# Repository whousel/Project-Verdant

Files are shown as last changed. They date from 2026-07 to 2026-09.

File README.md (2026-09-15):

# Project Verdant

## Automated Plant Monitoring \& Watering System

#### Giving plants the perfect start.

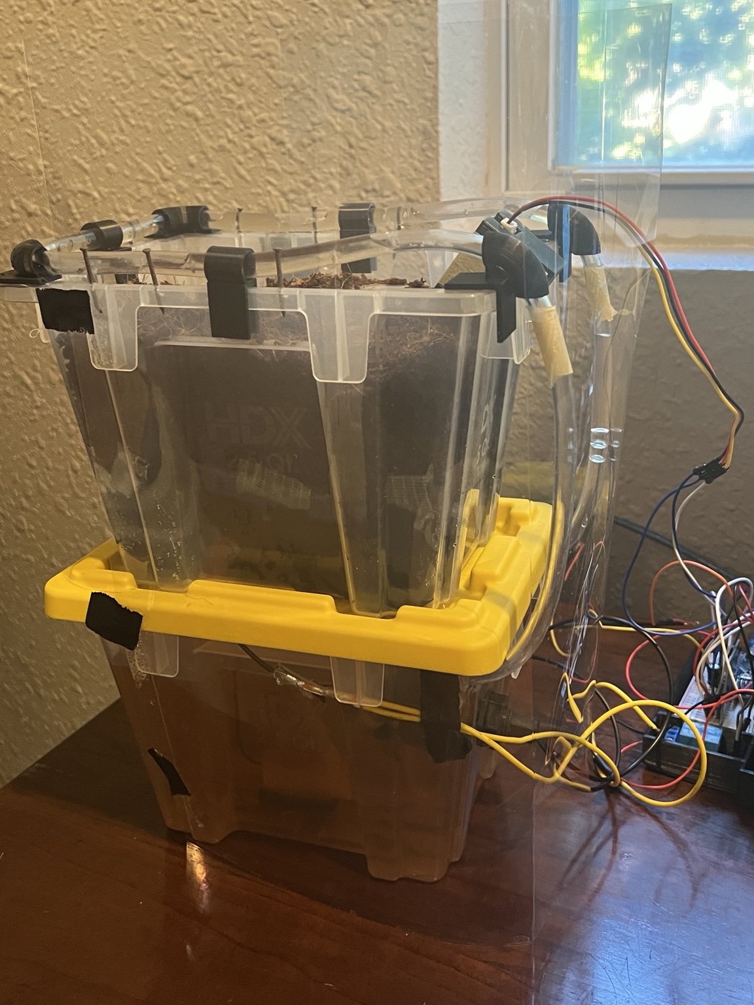
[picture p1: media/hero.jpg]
Project Verdant


### **Overview**

Project Verdant is an automated plant monitoring and watering system designed to reduce the need for manual plant care. The system continuously monitors soil moisture and reservoir water level, automatically activates a pump when the measured moisture falls below the configured threshold, and records system data to a MicroSD card for later analysis.

The project combines embedded software, electronics, CAD, 3D printing, and iterative physical testing into a single autonomous system.

### **Key Features**

\- Automatic soil moisture monitoring

\- Automatic watering based on configurable moisture thresholds

\- Reservoir water-level monitoring

\- MicroSD data logging

\- Pump control through a relay

\- Custom 3D-printed components

\- Distributed water delivery

\- Splash protection for electronics

\- LED status indication for data logging

\- Designed for extended unattended operation

### **How It Works**

The system continuously monitors the growing medium using a capacitive soil moisture sensor. When the measured moisture falls below the configured threshold, the Arduino Nano activates the water pump through a relay.

Water is distributed through multiple openings in the watering tubing to reduce concentrated water flow and provide more consistent coverage. A horizontal float switch monitors the reservoir water level.

Sensor readings and system states are recorded to a MicroSD card, allowing the system's behavior to be analyzed after testing.

```
                 ┌───────────────────┐
                 │ Soil Moisture      │
                 │ Sensor             │
                 └─────────┬─────────┘
                           │
                           ▼
┌───────────────┐    ┌──────────────┐
│ Water Level   │───►│ Arduino Nano │
│ Float Switch  │    └──────┬───────┘
└───────────────┘           │
                            │
             ┌──────────────┼──────────────┐
             │              │              │
             ▼              ▼              ▼
           Pump          MicroSD          LED
           Relay         Logging         Status
             │
             ▼
         Watering
          System
          
```
### **Hardware**

### **Electronics**

* Arduino Nano
* Capacitive soil moisture sensor
* Horizontal magnetic float switch
* Water pump
* Relay
* MicroSD card reader
* MicroSD card
* LED
* Resistor
* Capacitor
* Breadboard
* Jumper wires
* 9V power source

### **Mechanical System**

The prototype uses two 2.5-quart storage containers, one for the growing medium and one for the water reservoir.

Custom 3D-printed components are used to secure and route the pump and tubing, position the soil moisture sensor, and organize the electronics.

A clear acetate splash shield provides an additional layer of protection for the electronics.

CAD files for the custom components are available in the [`hardware/C.A.D`](hardware/C.A.D/) directory.

### **Software**

The Arduino software is responsible for:

1. Reading soil moisture.
2. Monitoring the reservoir water level.
3. Determining when watering is required.
4. Activating and deactivating the pump.
5. Recording sensor and system states.
6. Providing an LED indication of the data-logging state.

The current version uses local MicroSD storage rather than wireless data transfer. This keeps the system simple and allows testing data to be collected without requiring Wi-Fi or a separate application.

The primary project code is available in [`software/ProjectCode`](software/ProjectCode/).

Additional test programs used during development are also included in the [`software`](software/) directory.

### **Testing \& Validation**

Testing was performed iteratively throughout development, beginning with short functional tests and progressing to repeated extended-duration tests.

Three logged tests were completed to evaluate system behavior and sensor stability. Representative raw datasets are included in the [`data`](data/) directory.

### **Extended Monitoring**

During an uninterrupted test lasting approximately 44 minutes, measured soil moisture gradually decreased from approximately 55% to 48%.

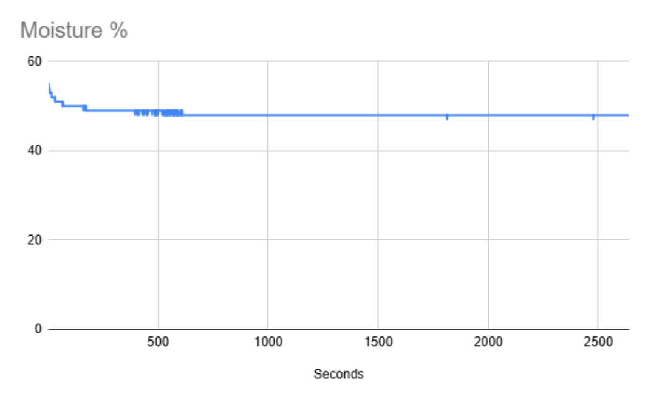
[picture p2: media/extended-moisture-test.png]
Extended moisture monitoring


The readings remained highly stable throughout the test, with no unexpected fluctuations or large measurement jumps.

### **Automatic Watering Response**

The coco coir used during testing retained moisture extremely well, so the system did not naturally reach the configured watering threshold during the extended monitoring tests.

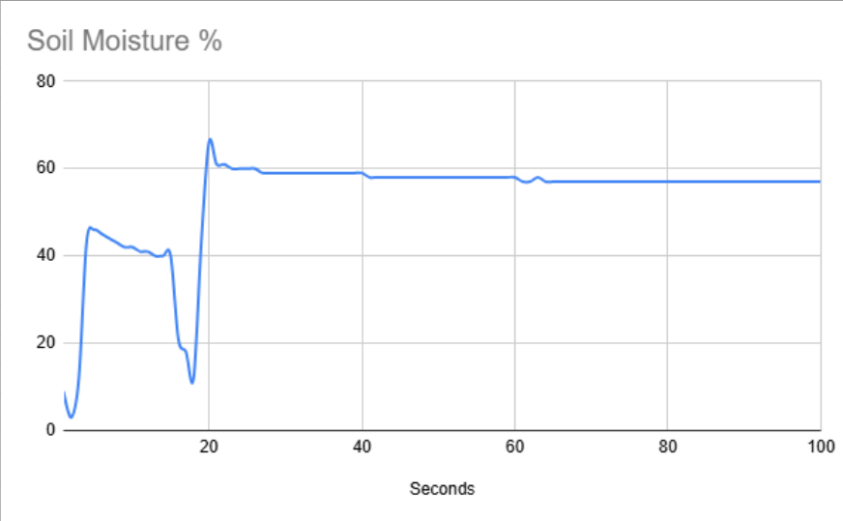
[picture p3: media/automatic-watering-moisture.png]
Automatic watering moisture response


The automatic watering response was therefore separately validated by intentionally removing the soil moisture sensor from the growing medium to simulate a dry condition.

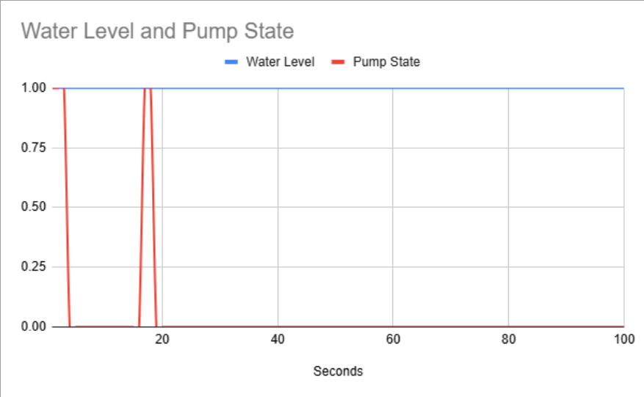
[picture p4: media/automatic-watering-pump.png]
Pump activation and water level


The measured moisture value decreased, causing the pump to activate. Returning the sensor to the growing medium caused the measured moisture value to increase and the pump to stop. This process was repeated multiple times.

The corresponding water-level and pump-state data shows the pump activating during the simulated dry conditions and stopping after the sensor was returned to the growing medium.

Representative raw datasets are available in [`data/`](data/).

### **Development Process**

Project Verdant was developed through repeated physical testing, failure analysis, redesign, and validation.

Several major design changes resulted directly from testing, including:

* Replacing the original water-level sensor with a horizontal float switch.
* Redesigning the watering tubing to address inconsistent water pressure.
* Adding tubing guides to prevent water from escaping the planter.
* Adding a splash shield after a pressure-related water event damaged an Arduino.
* Redesigning the pump holder and other 3D-printed components.
* Adding an LED indicator for MicroSD data logging.
* Adding MicroSD data logging for extended testing.
* Improving electrical connections to prevent intermittent sensor disconnections.

The [`development log`](docs/devlog.md) documents the project's progression from initial prototype through the completed V1 system.

### **Engineering Decisions**

The reasoning behind major hardware and design choices is documented in [`decisions.md`](docs/decisions.md).

These include the choice of:

* A capacitive soil moisture sensor
* A horizontal float switch
* Two stacked storage containers
* MicroSD data logging
* An Arduino Nano
* A splash shield
* Distributed watering tubing and tubing guides

### **Requirements**

The original and completed Version 1 requirements, along with planned future functionality, are documented in [`requirements`](docs/requirements.md).

### **Bill of Materials**

The estimated cost of the prototype is documented in the [`bill of materials`](docs/bill%20of%20materials.md).

Component costs are based on the portion of each purchased component used in the prototype. Multi-packs are accounted for using the estimated cost of the individual components used.

### **Future Development**

Project Verdant is intended to continue beyond the current prototype.

### **Plant Profiles**

Add predefined plant profiles with different moisture requirements. Users will eventually be able to select and modify plant profiles and adjust settings directly on the device or through an application.

### **Environmental Monitoring**

Add temperature and airflow monitoring and eventually incorporate these measurements into plant-care decisions.

### **Improved Watering**

Redesign the watering system to provide more consistent and reproducible water distribution while reducing the amount of manual setup required.

### **User Experience**

Develop a more refined external enclosure, improve the LED indicator system, make the reservoir easier to refill, and improve access to components for maintenance.

### **Safety and Reliability**

Continue improving protection against water and electrical damage and increase the system's ability to operate safely for extended periods without supervision.

### **Expanded Applications**

Explore the use of nutrient-enriched water and potential adaptation of the system for hydroponic and other automated growing applications.

### **Repository Structure**

Project-Verdant/

├── [`software/`](software/) — Arduino source code

├── [`hardware/C.A.D/`](hardware/C.A.D/) — CAD and 3D-printable parts

├── [`data/`](data/) — representative test datasets

├── [`media/`](media/) — project images and test graphs

└── [`docs/`](docs/) — requirements, decisions, development log, and bill of materials

### **Lessons Learned**

Project Verdant has been developed through repeated testing, failure, redesign, and validation.

The most significant lessons came from problems that were not apparent in the initial design. Water pressure, tubing geometry, sensor behavior, electrical connections, and water protection all required physical testing before the system became reliable.

The current prototype is the result of these iterative improvements rather than a single successful build.

### **Current Status**

Version 1 — Functional

The current prototype successfully monitors soil moisture and reservoir level, automatically controls watering, logs system data, and has completed repeated extended-duration tests without water escaping the intended system.

Development of additional features and improvements is ongoing.

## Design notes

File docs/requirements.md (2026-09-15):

# **Project-Verdant  — Requirements**

### **Version 1 — Completed**

##### **Monitoring**

* Continuously monitor soil moisture.
* Monitor the water level of the reservoir.
* Detect when the reservoir is empty or below the required water level.
* Provide a visible LED indicator for the data-logging system.

##### **Automatic Watering**

* Automatically activate the pump when soil moisture falls below the configured threshold.
* Automatically stop watering when the desired moisture level is reached.
* Deliver water through a distributed watering system designed to provide more consistent coverage.
* Keep water contained within the planter and reservoir during operation. 

##### **Data Logging**

* Record soil moisture readings over time.
* Record water-level status.
* Record pump state.
* Store testing data on a microSD card for later analysis.

##### **Reliability and Safety**

* Operate continuously without requiring manual intervention during normal operation.
* Protect the electronics from accidental water exposure.
* Prevent water from escaping the intended watering area.
* Maintain stable operation during extended testing.
* Use a splash shield as an additional layer of protection for the electronics.

##### **Physical Design**

* Use custom 3D-printed components to secure and route system components.
* Secure the pump and watering tubing.
* Provide a compact enclosure for the primary electronics.
* Use removable containers for the reservoir and growing medium.

### **Future Development — Planned**

##### **Plant-Specific Control**

* Add predefined plant profiles with different recommended moisture conditions.
* Allow users to select and modify plant profiles.
* Allow watering thresholds and other settings to be changed directly on the device or through an application.

##### **Environmental Monitoring**

* Add temperature monitoring.
* Add airflow monitoring.
* Use environmental data to improve watering decisions and plant care.

##### **Improved Watering**

* Redesign the watering system for more consistent water distribution.
* Improve pressure regulation and water flow.
* Improve drainage and water routing.
* Make the system easier to refill.

##### **User Experience**

* Develop a more refined external enclosure.
* Improve the LED indicator system and integrate it into the enclosure.
* Improve the overall appearance and organization of the system.
* Make maintenance, refilling, and component access easier.

##### **Safety and Reliability**

* Improve protection against water exposure and electrical damage.
* Improve long-term unattended operation.
* Continue testing toward a system that can safely operate for extended periods without supervision.
* Improve the reliability of mechanical and electrical connections.

##### **Expanded Applications**

* Support nutrient-enriched water when appropriate for the selected growing method.
* Explore adaptation for hydroponic and other automated growing applications.

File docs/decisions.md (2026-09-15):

# Project-Verdant - Decisions

**I plan to replace my current water level sensors with side-mounted float switches -**  This will let me track the water level more accurately, track larger changes in the water level, and allow me to skip the stabilization period associated with my current water level sensor. The float switch will provide a much simpler and immediate indication of the level of water remaining in the reservoir.

**I am using a capacitive soil moisture sensor instead of a resistive sensor -** This is because the capacitive soil moisture sensor is much more accurate than the resistive sensor, and the resistive sensor is prone to electrolysis due to conductive probes exposed directly to soil. This switch should greatly improve the lifespan of the soil moisture sensor.

**I am using 2 2.5-quart storage containers to hold the soil and water, respectively -** I chose to stack and use these two containers because they felt like they were of much better quality than the standard 2.5-quart plastic containers, and because they were made to be stacked. Their improved durability allows me to drill into and modify the containers without fear of their collapse, and it gives me confidence in putting relatively heavy objects in them over extended periods without significant wear.

**I distributed the water across multiple openings in the tubing -** I wanted to avoid concentrating the pump’s output in one location, which could disturb the growing medium and cause uneven watering. Distributing the water across multiple openings allows the water to spread across the growing area more evenly. This design is functional for the current prototype, but I plan to replace it with a more consistent watering method in a future version because manually creating and sizing the openings is difficult to reproduce consistently.

**I added nails to guide the watering tubing over the planter walls -** When the pump starts or stops, the water pressure temporarily changes and water can run along the outside of the tubing instead of exiting through the intended holes. Without a guide, this water could run over the edge of the planter and onto the surrounding surface. The nails guide the tubing over the planter so that any water following the outside of the tubing remains within the growing area.

**I added a clear acetate splash shield around the electronics -** During testing, a sudden increase in water pressure caused water to spray throughout the system and damaged an Arduino. I added the splash shield to prevent water from reaching the electronics if another pressure-related issue occurs. Although later improvements reduced the likelihood of water escaping the intended area, I decided to keep the splash shield as an additional layer of protection.

**I am using a MicroSD card for data logging instead of wireless data transfer -** I chose MicroSD logging because it allows the system to record data without requiring Wi-Fi, a network connection, or a separate application. This keeps the system simpler and easier to deploy while still allowing me to collect and analyze data after testing. The MicroSD module was also inexpensive and straightforward to integrate with the Arduino Nano.

**I am using an Arduino Nano as the primary microcontroller -** The Nano provides enough inputs and outputs for the sensors, pump control, LED, and MicroSD module used in this project while being significantly smaller and less expensive than larger Arduino boards. The additional capabilities of a larger board were not necessary for the requirements of Version 1.

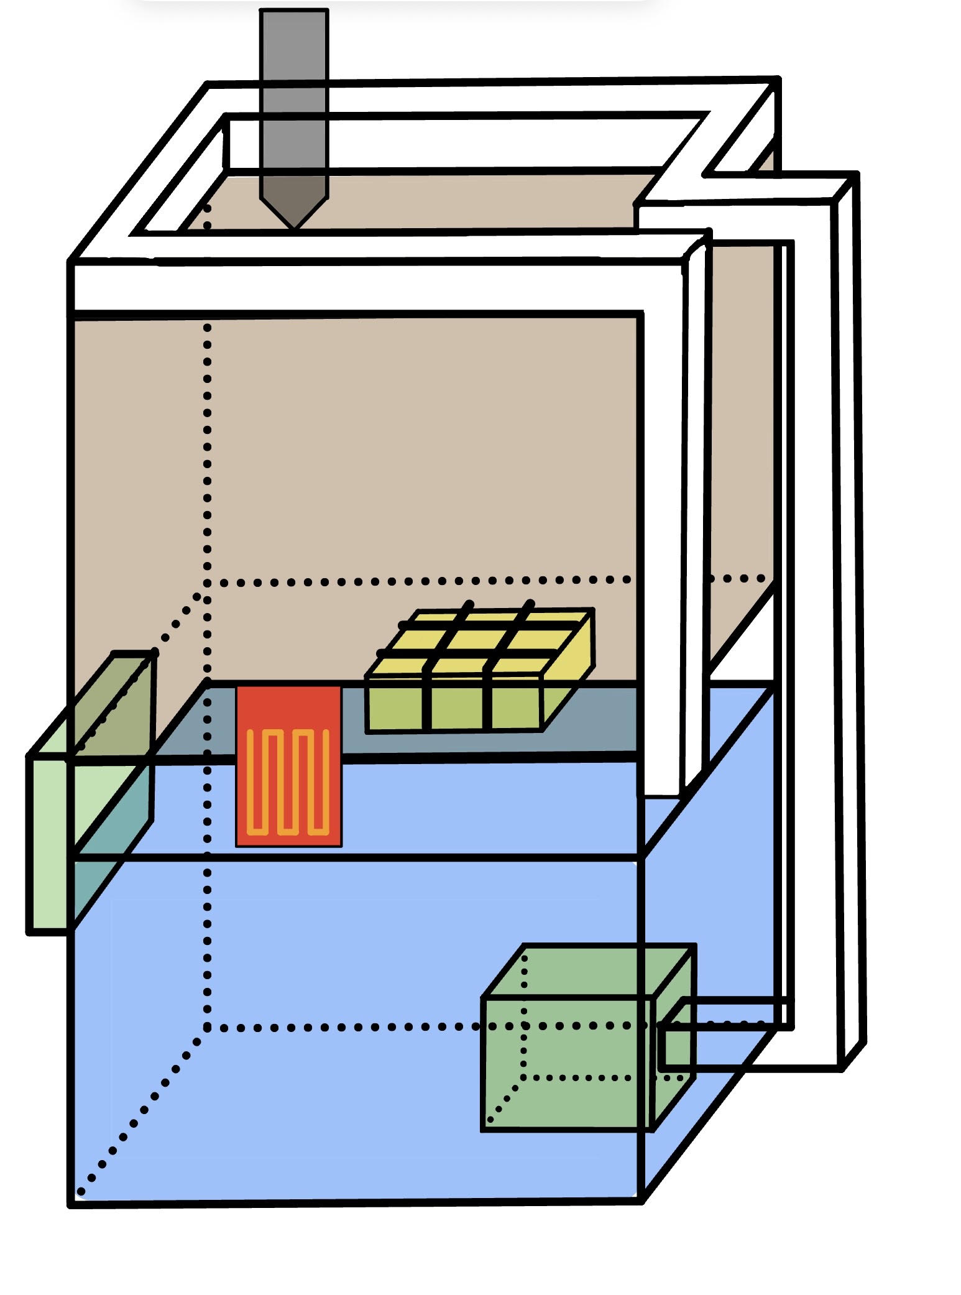
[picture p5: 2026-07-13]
media/Prototype Version 1.jpg

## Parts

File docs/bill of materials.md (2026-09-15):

# Project-Verdant - Bill of Material

#### 

#### **Electronics**

|**Component**|**Quantity**|**Estimated Cost**|
|-|-|-|
|Arduino Nano|1|$4.00|
|Breadboard|1|$2.50|
|Capacitive soil moisture sensor|1|Included in $4.00 bundle|
|Horizontal float switch|1|$3.00|
|Water pump|1|Included in $4.00 bundle|
|Relay|1|Included in $4.00 bundle|
|SD card reader module|1|$1.20|
|MicroSD card|1|$10.00|
|LED|1|\~$0.10|
|Resistor|1|\~$0.10|
|Capacitor|1|\~$0.10|
|Jumper wires|Several|\~$0.25|
|9V battery and connector|1|\~$1.50|

#### **Mechanical Components**

|**Component**|**Quantity**|**Estimated Cost**|
|-|-|-|
|Screws / fasteners|Several|\~$0.25|
|2.5-quart containers|2|$5.00|
|Clear tubing|\~3 ft|\~$0.78|
|Nails|Several|\~$0.10|
|3D-printing filament|\~100 grams|\~2|
|Clear acetate sheet|1|TBD|
|Coco coir / growing medium|—|\~$1.00|

##### **Cost Notes**

Component costs are estimated from the purchase price of the materials used in the prototype. When components were purchased in multi-packs, the estimated cost of one component was used rather than the full package price. Small consumables such as filament, nails, screws, resistors, and LEDs are estimated based on the portion actually used in the prototype.

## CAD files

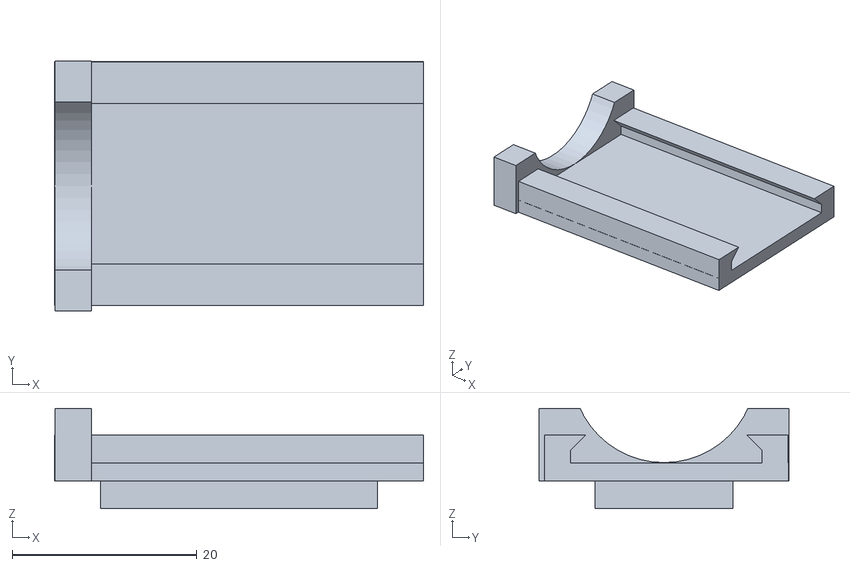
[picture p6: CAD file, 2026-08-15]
hardware/C.A.D/Pump holder v2.stl
40.0 x 27.1 x 10.9

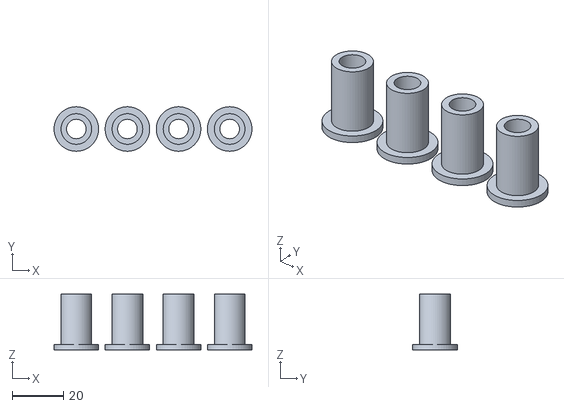
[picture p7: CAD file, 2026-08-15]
hardware/C.A.D/Drainage hole Aligners.stl
77.5 x 17.5 x 21.8

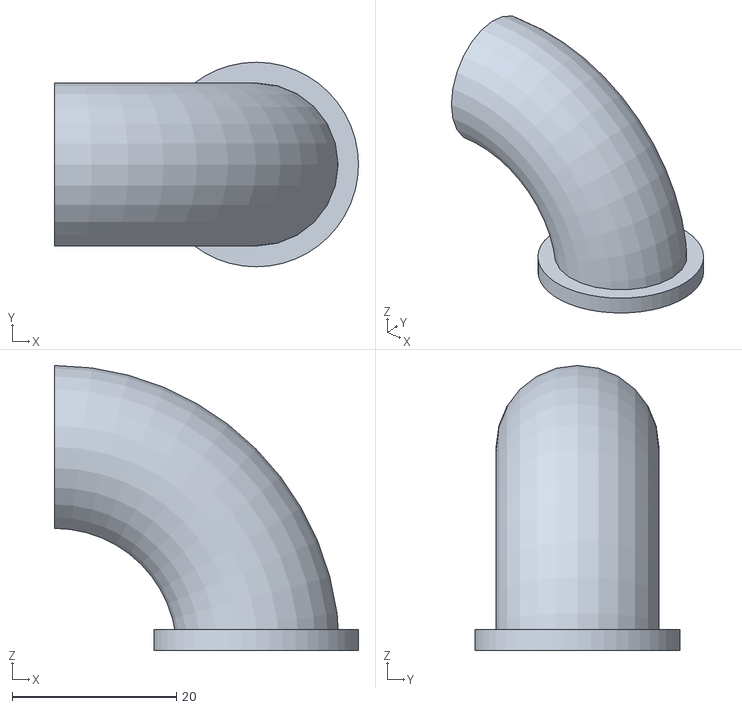
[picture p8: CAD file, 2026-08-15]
hardware/C.A.D/Water Pump Excess Tubing.stl
37.0 x 24.9 x 34.7

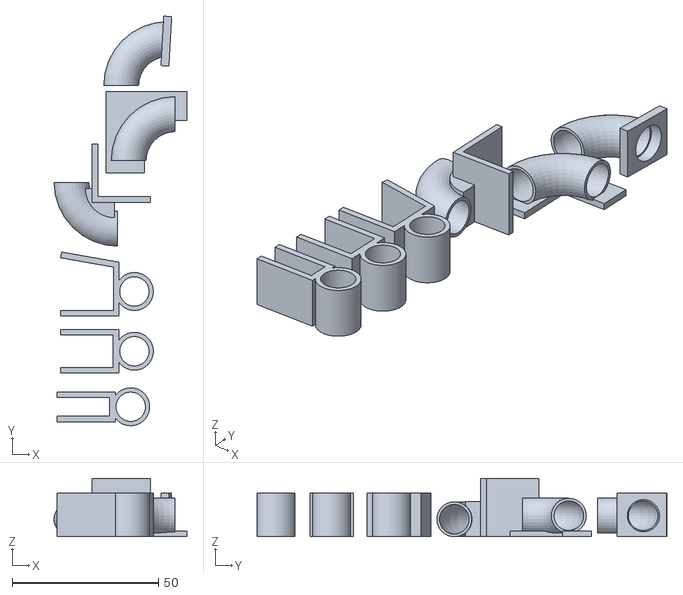
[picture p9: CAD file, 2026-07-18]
hardware/C.A.D/Update Tube Routing Clips.stl
45.5 x 140.1 x 20.0

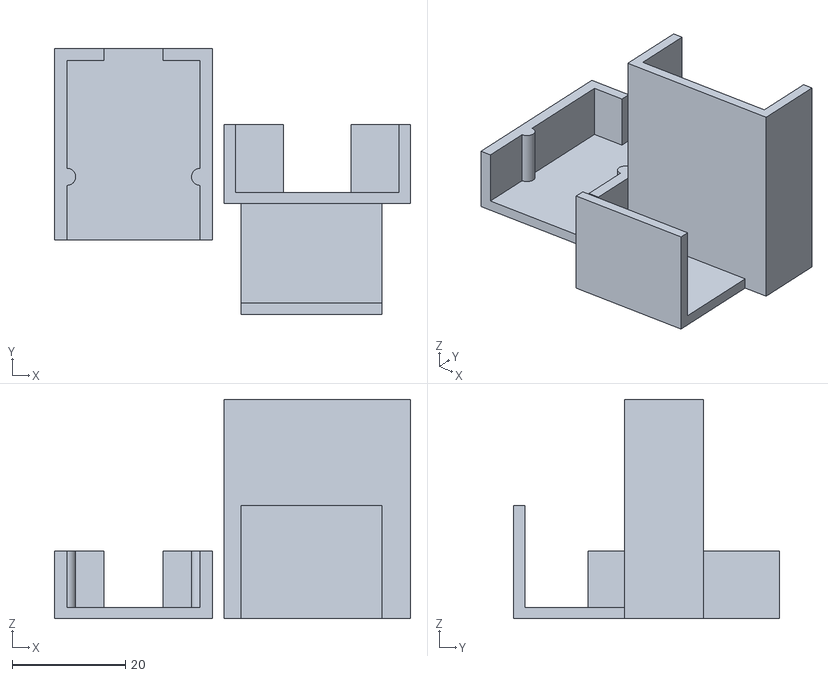
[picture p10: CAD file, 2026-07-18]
hardware/C.A.D/Soil Moisture Sensor Holder - Test.stl
63.0 x 47.0 x 38.8

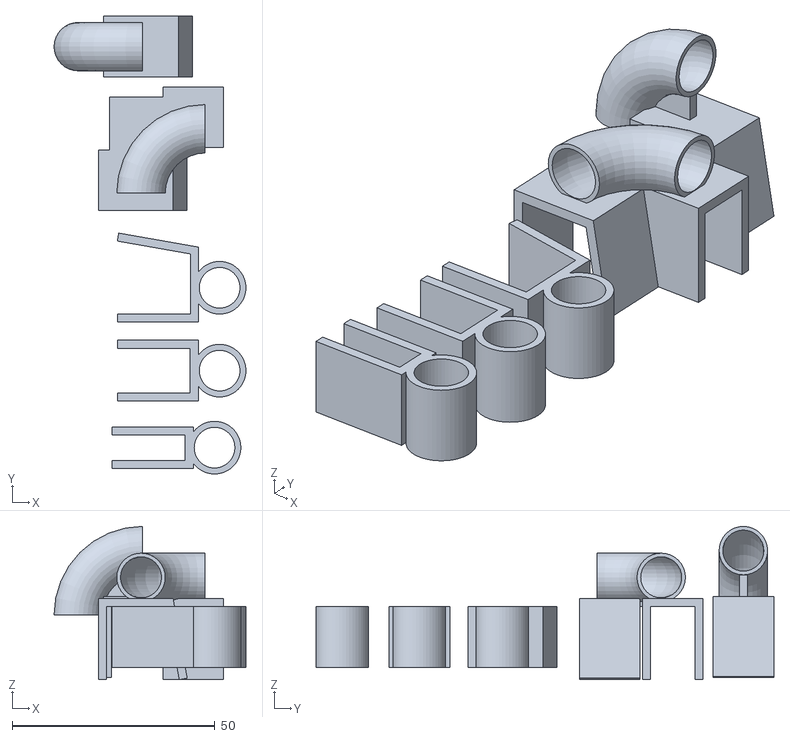
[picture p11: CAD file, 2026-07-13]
hardware/C.A.D/Watering Tubing Clip - Test.stl
47.4 x 113.0 x 37.8

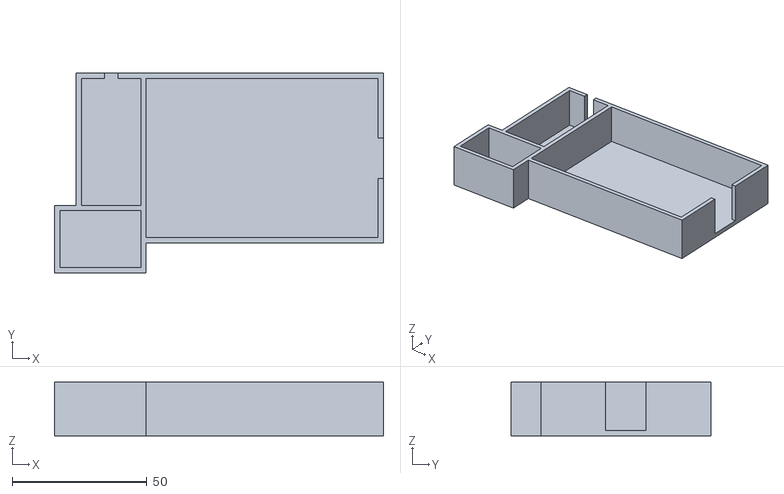
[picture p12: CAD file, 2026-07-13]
hardware/C.A.D/Arduino Prototype Housing - Test.stl
122.0 x 74.0 x 20.0

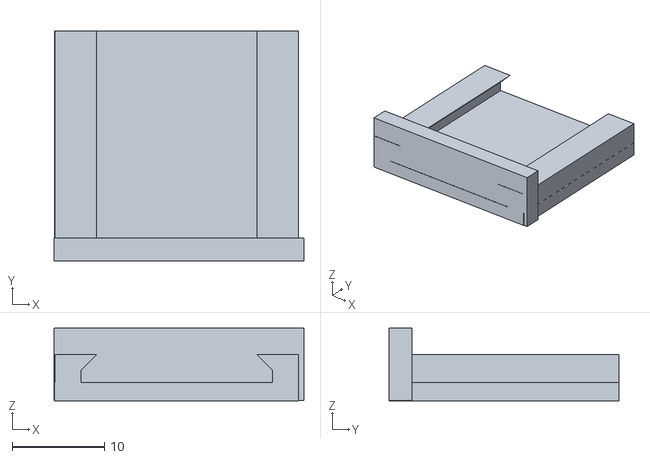
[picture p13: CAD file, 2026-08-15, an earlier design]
hardware/C.A.D/Pump holder v1.stl
27.1 x 25.0 x 7.88

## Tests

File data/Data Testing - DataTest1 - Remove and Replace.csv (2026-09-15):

Seconds | Moisture % | Water Level | Pump State
1 | 23 | 1 | 0
2 | 23 | 1 | 0
3 | 23 | 1 | 0
4 | 23 | 1 | 0
5 | 23 | 1 | 0
6 | 23 | 1 | 0
7 | 23 | 1 | 0
8 | 23 | 1 | 0
9 | 22 | 1 | 0
10 | 3 | 1 | 1
11 | 0 | 1 | 1
12 | 0 | 1 | 1
13 | 0 | 1 | 1
14 | 0 | 1 | 1
15 | 0 | 1 | 1
16 | 0 | 1 | 1
17 | 11 | 1 | 1
18 | 36 | 1 | 0
19 | 40 | 1 | 0
20 | 40 | 1 | 0
21 | 40 | 1 | 0
22 | 40 | 1 | 0
23 | 15 | 1 | 1
24 | 7 | 1 | 1
25 | 6 | 1 | 1
26 | 6 | 1 | 1
27 | 6 | 1 | 1
28 | 10 | 1 | 1
29 | 37 | 1 | 0
30 | 36 | 1 | 0
31 | 35 | 1 | 0
32 | 33 | 1 | 0
33 | 32 | 1 | 0
34 | 31 | 1 | 0
35 | 30 | 1 | 0
36 | 30 | 1 | 0
37 | 29 | 1 | 0
38 | 29 | 1 | 0
39 | 28 | 1 | 0
40 | 28 | 1 | 0
41 | 28 | 1 | 0
42 | 28 | 1 | 0
43 | 27 | 1 | 0
44 | 27 | 1 | 0
45 | 27 | 1 | 0
46 | 26 | 1 | 0
47 | 26 | 1 | 0
48 | 26 | 1 | 0
49 | 26 | 1 | 0
50 | 26 | 1 | 0
51 | 26 | 1 | 0
52 | 26 | 1 | 0
53 | 26 | 1 | 0
54 | 25 | 1 | 0
55 | 25 | 1 | 0
56 | 25 | 1 | 0
57 | 25 | 1 | 0
58 | 25 | 1 | 0
59 | 25 | 1 | 0
60 | 25 | 1 | 0
61 | 25 | 1 | 0
62 | 25 | 1 | 0
63 | 24 | 1 | 0
64 | 26 | 1 | 0
65 | 27 | 1 | 0
66 | 25 | 1 | 0
67 | 40 | 1 | 0
68 | 32 | 1 | 0
69 | 32 | 1 | 0
70 | 32 | 1 | 0
71 | 32 | 1 | 0
72 | 30 | 1 | 0
73 | 30 | 1 | 0
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

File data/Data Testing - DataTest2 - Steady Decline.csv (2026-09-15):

Seconds | Moisture % | Water Level | Pump State
1 | 55 | 1 | 0
2 | 55 | 1 | 0
3 | 55 | 1 | 0
4 | 54 | 1 | 0
5 | 54 | 1 | 0
6 | 54 | 1 | 0
7 | 54 | 1 | 0
8 | 53 | 1 | 0
9 | 53 | 1 | 0
10 | 53 | 1 | 0
11 | 53 | 1 | 0
12 | 53 | 1 | 0
13 | 53 | 1 | 0
14 | 53 | 1 | 0
15 | 53 | 1 | 0
16 | 53 | 1 | 0
17 | 52 | 1 | 0
18 | 52 | 1 | 0
19 | 52 | 1 | 0
20 | 52 | 1 | 0
21 | 52 | 1 | 0
22 | 52 | 1 | 0
23 | 52 | 1 | 0
24 | 52 | 1 | 0
25 | 52 | 1 | 0
26 | 52 | 1 | 0
27 | 52 | 1 | 0
28 | 52 | 1 | 0
29 | 52 | 1 | 0
30 | 52 | 1 | 0
31 | 51 | 1 | 0
32 | 52 | 1 | 0
33 | 52 | 1 | 0
34 | 51 | 1 | 0
35 | 51 | 1 | 0
36 | 51 | 1 | 0
37 | 51 | 1 | 0
38 | 51 | 1 | 0
39 | 51 | 1 | 0
40 | 51 | 1 | 0
41 | 51 | 1 | 0
42 | 51 | 1 | 0
43 | 51 | 1 | 0
44 | 51 | 1 | 0
45 | 51 | 1 | 0
46 | 51 | 1 | 0
47 | 51 | 1 | 0
48 | 51 | 1 | 0
49 | 51 | 1 | 0
50 | 51 | 1 | 0
51 | 51 | 1 | 0
52 | 51 | 1 | 0
53 | 51 | 1 | 0
54 | 51 | 1 | 0
55 | 51 | 1 | 0
56 | 51 | 1 | 0
57 | 51 | 1 | 0
58 | 51 | 1 | 0
59 | 51 | 1 | 0
60 | 51 | 1 | 0
61 | 51 | 1 | 0
62 | 51 | 1 | 0
63 | 51 | 1 | 0
64 | 51 | 1 | 0
65 | 51 | 1 | 0
66 | 50 | 1 | 0
67 | 50 | 1 | 0
68 | 50 | 1 | 0
69 | 51 | 1 | 0
70 | 50 | 1 | 0
71 | 50 | 1 | 0
72 | 50 | 1 | 0
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

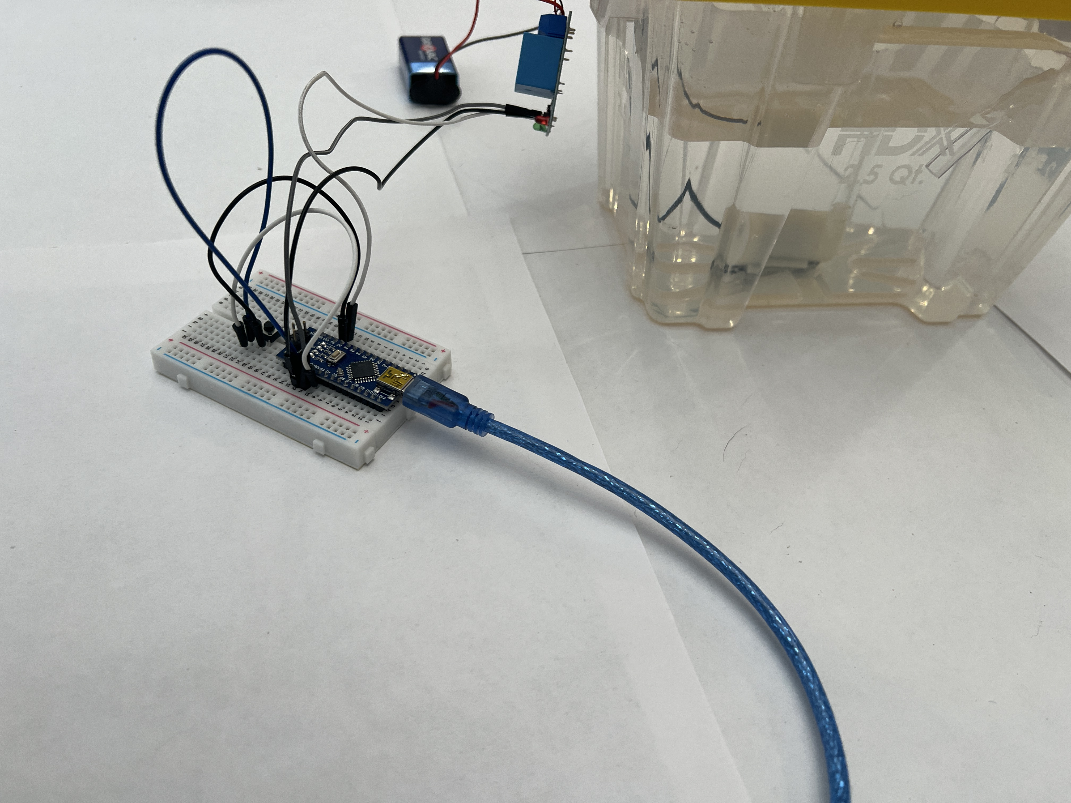
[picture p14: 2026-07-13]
media/Watering System Pump Test - No Holes (3).jpeg

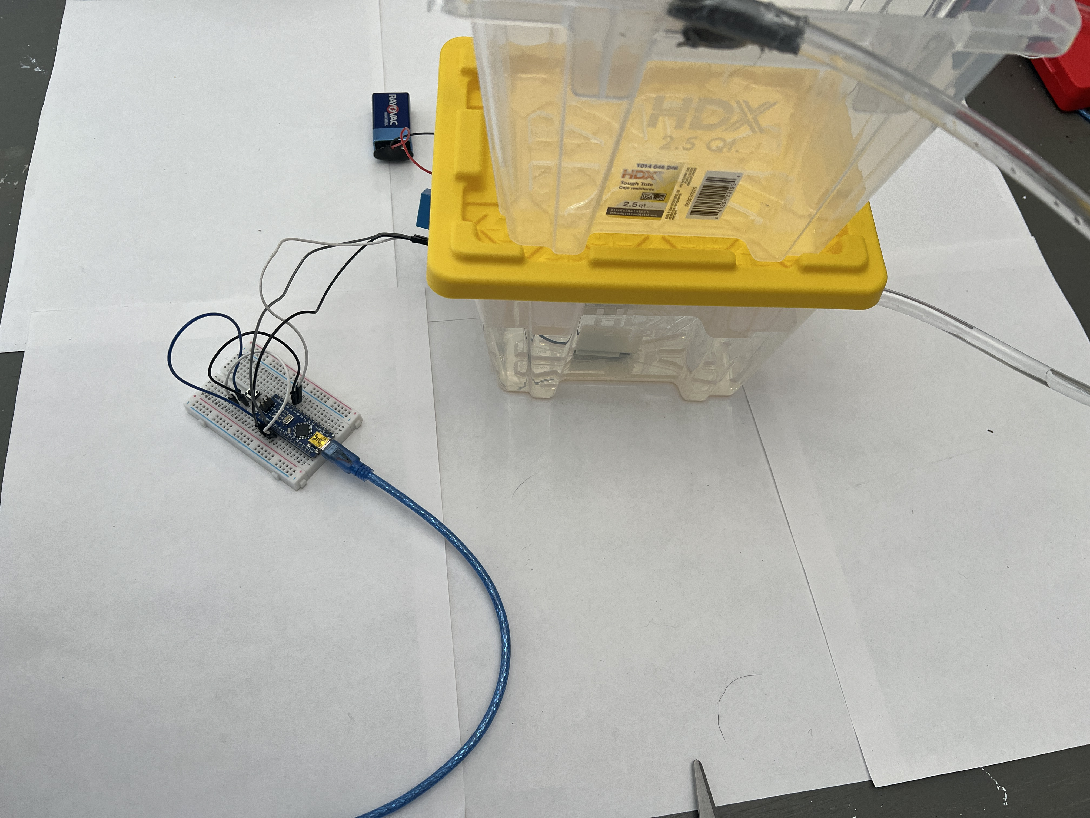
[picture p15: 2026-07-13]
media/Watering System Pump Test - No Holes (2).jpeg

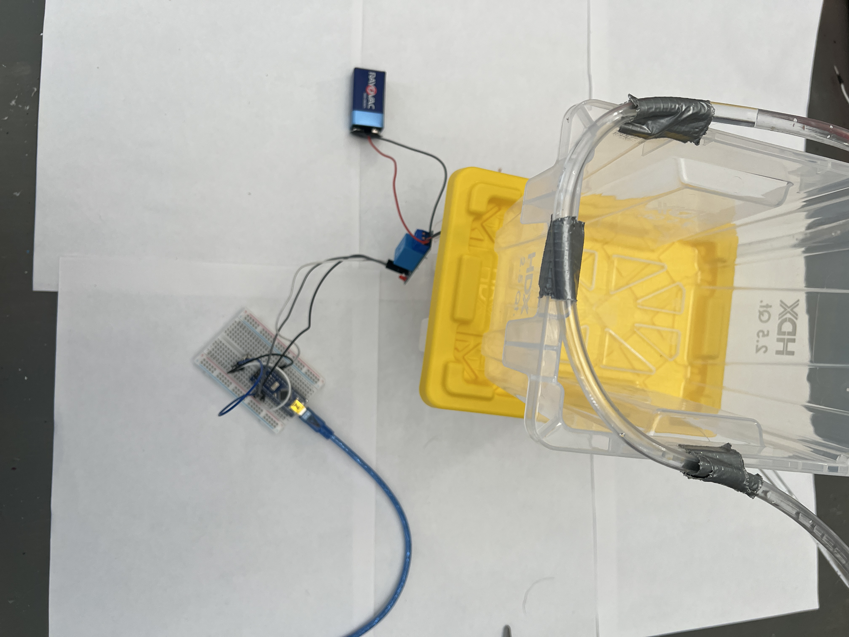
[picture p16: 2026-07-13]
media/Watering System Pump Test - No Holes (1).jpeg

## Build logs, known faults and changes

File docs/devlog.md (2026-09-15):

# \# Project-Verdant

# 

# \## July 8, 2026

# 

Created a GitHub repository, defined a successful version 1, and finished project planning. Tomorrow, I plan to relearn circuit design and how to use analog inputs with an Arduino.

# 

# \# July 9, 2026

# 

Developed code and a working prototype that successfully reads the soil moisture percentage based on tested wet and dry values and turns the pump on or off to maintain adequate soil moisture. Currently facing issues with water depth detection due to non-waterproof components. Ran into issues with the water-level sensor displaying seemingly random values that subsided after a 100 ms delay from when it turned on to its measuring point. Successfully coded and added the water level sensor to the prototype circuit.

# 

# \# July 10, 2026

# 

Sketched the initial version 1 prototype layout. Tested and integrated the water level sensor into the current build. Through testing, I ran into an issue with extremely irregular and unstable readings, which, through more testing, I learned arose from a stabilization period that the current water level sensor required.

# 

# \# July 11, 2026

# 

Designed the prototype housing for Arduino. Encountered repeated issues with the Arduino disconnecting during testing with the new watering system. After many attempts at taking the prototype apart, rewiring, and checking the code, I decided to replace all current parts, which solved the issue. At a later date, I will test each individual sensor and connection to see what caused the issue. Wrote a temporary test program for the pump so that I could see the effectiveness of the new watering system with the new container design. Ran into a kinking problem with the tubing, which I plan to solve using 3d modeled connectors, preventing hard angels better guiding the tubing.

# 

# \# July 12, 2026

# 

Designed the clips to prevent kinking and guide the tubing for the watering system. Bought digital calipers to accurately measure parts for 3d modeling, a micro SD card for which I could log data during extended testing, more vinyl tubing allowing for more testing for different and possibly more efficient watering system designs, side-mounted magnetic float sensors to replace my current subpar water level sensor, and a connector between the Arduino and the micro SD card. Started 3d printing the temporary housing for the Arduino and the tube clips.

# 

# \# July 15, 2026

# 

Redesigned clips to minimize print failures and better route tubing. Prepared tube routing clips for printing.

# 

# \# July 16, 2026

# 

Coded and tested side-mounted magnetic float sensors. Verified the ability to accurately and quickly check for the presence of water. Used code from HuHamster’s YouTube channel to test the MicroSD card module’s ability to save various plant habitat data to an external drive.

# 

# \# July 17, 2026

# 

Overhauled project code to use the new MicroSD card module and side-mounted magnetic float sensors. Lightly cleaned and commented on code to improve readability. Began printing the various tube routing clips.

# 

# \# July 30, 2026

# 

Attached clips to housing and began assembly of prototype 1 v1

# 

# \# July 31, 2026

# 

Purchased a CNC machine to manufacture parts for the build

# 

# \# Aug 1, 2026

# 

Finished assembly of prototype v1. Tested the functionality and documented the following issues: leakage from the side-mounted horizontal float switch, not able to tell if the SD card is behaving correctly, lack of drainage holes, lack of holes in the watering tubing, the pump attachment is not attached securely, need to direct the excess water tubing into the reservoir.

# 

# \# Aug 4, 2026

# 

3d modeled the excess water guide, secure pump attachment, and water drainage tubes. Began printing the CAD models.

# 

# \# Aug 6, 2026

# 

Added an LED indicator acting as a sticky state indicator showing whether the SD card is receiving data correctly.

# 

# \# Aug 8, 2026

# 

Installed new CAD designs onto the apparatus. Redesigned the pump holder, printed a new model, and installed it.

# 

# \# Aug 14, 2026

# 

Started adding holes to the water tubing. Encountered issues with inconsistent water pressure. Holes near the pump sprayed water, while holes at the end of the tubing had water trickling out. When the pump first turns on, the water pressure spikes and sprays water everywhere, soaking my electronics and killing a nano. Unfortunately, the nano showed a white substance, which I found out may be a mineral buildup from the water hitting it directly. Even after cleaning with 91% isopropyl alcohol, the Arduino remained useless and inoperable. Encountered issues: Need a splash shield to protect from water damage, pressure issues, need to improve drainage tubing attachment, need a way to, temporarily, secure the filter to the base of the plant container, current pump clips allow for water to leave the container if pressure is low, and lastly experiencing some issues with a lack of data being written to the SD card that needs to be investigated.

# 

# \# August 16, 2026

# 

Added a clear acetate splash shield to protect the Arduino from water. Kinked the end of the tubing with a zip tie to help even out the water pressure and allow the water to flow more evenly.

# 

# \# August 21, 2026

# 

The kinked tubing solved the low-pressure issue flawlessly. The new higher pressure caused water to spray throughout the system, but the splash shield successfully protected the electronics. Added more holes to the watering tubing to further even out the pressure and water the soil more consistently. Water was sometimes running down the outside of the tubing and flowing over the wall of the planter, so I drilled holes and added nails to guide the tubing over the planter area. This was the first fully successful test where there were no leaks, all water remained contained within the setup, and there were no other issues. The system successfully ran for one minute before I unplugged it. Planned to add soil the following day.

# 

# \# August 25, 2026

# 

It works! Fixed a common disconnection issue that was preventing prolonged testing by modifying the wires connected to the horizontal float switch. Reconstructed a large portion of the unit after it was damaged while moving it into my college dorm. Added soil and successfully tested both the filter and the ability to turn the pump on and off at different soil moisture readings. Added and watered the soil repeatedly until it stopped settling. Modified the splash shield to fit the assembly more securely and make it easier to install. Although the splash shield is no longer required for normal operation, it is still useful as an additional safety measure. Ran a two-minute uninterrupted test five consecutive times without a single issue or drop of water escaping the setup. The SD card was not detected, so these tests could not be logged.

# 

# \# August 26–September 3, 2026

# 

Ran repeated 30–45 minute tests over multiple days to verify the reliability of the system during extended operation. Every test completed successfully without leaks, water escaping the setup, or other system failures. Added data logging to the testing process and completed three logged tests. The data showed stable and consistent soil moisture readings throughout the tests. One extended test showed a gradual decrease in soil moisture from approximately 55% to 48% over roughly 44 minutes without unexpected fluctuations. Additional testing by intentionally removing the soil moisture sensor from the growing medium successfully triggered the watering system, and returning the sensor to the growing medium produced the expected increase in moisture readings.

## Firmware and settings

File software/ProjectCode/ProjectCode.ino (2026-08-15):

//code by William Housel

#include <SPI.h>
#include <SD.h>

const int MOISTURESENSOR = A1; //the sensor to read
const int PUMP = 2; //the pin connecting to the pump's input
const int WET = 230; //sensor reading for wet
const int DRY = 615; //sensor reading for dry
const int WET_THRESHOLD = 80; 
const int DRY_THRESHOLD = 20;
const int floatSwitchPin = 4;

const int chipSelect = 10; //activates the SD card module.

unsigned long seconds; //seconds since cycle began, changed to long to prevent int overflow
int soilMoistureState; //soil moisture percentage
int waterLevelState; //0 = Empty, 1 = Full
int pumpState; //0 = Off, 1 = On

const unsigned long LOG_INTERVAL  = 1000;
unsigned long logTimer = 0;

const int SD_CARD_FUNCTION_PIN = 3;


void setup() {
  Serial.begin(9600);
  pinMode(MOISTURESENSOR, INPUT);
  pinMode(PUMP, OUTPUT);
  pinMode(floatSwitchPin, INPUT_PULLUP); 
  pinMode(SD_CARD_FUNCTION_PIN, OUTPUT);



  digitalWrite(PUMP, HIGH); //ensures the pump starts off
  digitalWrite(SD_CARD_FUNCTION_PIN, LOW);
  Serial.println("Seconds, Moisture %, Water Level, Pump State");
  delay(100); //gives the SD card reader a chance to turn on and stabilize
  if (!SD.begin(chipSelect)) 
  {
    Serial.println("SD initialization failed! Check card/wiring.");
    digitalWrite(SD_CARD_FUNCTION_PIN, HIGH);

  } 
  else 
  {
    Serial.println("SD card initialized successfully.");
  }

  //prints the headers to data.txt for easy graphing
  File dataFile = SD.open("data.txt", FILE_WRITE);
    
    if (dataFile) {
      
      dataFile.println("Seconds, Moisture %, Water Level, Pump State");
      dataFile.close(); 
    }
    else 
    {
      Serial.println("Error accessing the SD card");
      digitalWrite(SD_CARD_FUNCTION_PIN, HIGH);

    }

}
 
void loop() {
  unsigned long currentTime = millis();
  if (currentTime - logTimer >= LOG_INTERVAL )
  {
    seconds = currentTime/1000;
      
      findWaterLevel(); //changed to use side mounted magnetic float switch
      moistureLevel();
      
      logTimer = currentTime;

    File dataFile = SD.open("data.txt", FILE_WRITE);
    
    if (dataFile) {
      
      dataFile.print(seconds);
      dataFile.print(",");
      dataFile.print(soilMoistureState);
      dataFile.print(",");
      dataFile.print(waterLevelState);
      dataFile.print(",");
      dataFile.println(pumpState);
      
      
      dataFile.close(); 
    } 
    else 
    {
      Serial.println("Error accessing the SD card");
      digitalWrite(SD_CARD_FUNCTION_PIN, HIGH);

    }
      //printing the actions as comma seperated values (csv) for easy tracking
      Serial.print(seconds);
      Serial.print(",");
      Serial.print(soilMoistureState);
      Serial.print(",");
      Serial.print(waterLevelState);
      Serial.print(",");
      Serial.println(pumpState);
  }

}
void moistureLevel()
{
  int value = analogRead(MOISTURESENSOR);
  int moisturePercentageRaw = map(value, WET, DRY, 100, 0); 
  int moisturePercentage = constrain(moisturePercentageRaw,0,100);
  if (moisturePercentage >= WET_THRESHOLD)
  {
    digitalWrite(PUMP, HIGH);
    pumpState = 0;
  }
  else if (moisturePercentage >= DRY_THRESHOLD)
  {
    digitalWrite(PUMP, HIGH);
    pumpState = 0;
  }
  else if (waterLevelState == 1)
  {
    digitalWrite(PUMP, LOW);
    pumpState = 1;
  }
  else
  {
    digitalWrite(PUMP, HIGH);
    pumpState = 0;
  }
  soilMoistureState = moisturePercentage;
}
void findWaterLevel() 
{
  int switchState = digitalRead(floatSwitchPin);
  if (switchState == LOW) 
  {
    waterLevelState = 1;
  } 
  else 
  {
    waterLevelState = 0;
  }
}          
                    

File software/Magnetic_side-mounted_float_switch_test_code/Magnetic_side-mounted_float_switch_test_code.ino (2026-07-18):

const int floatSwitchPin = 2;

void setup() {
  Serial.begin(9600);
  pinMode(floatSwitchPin, INPUT_PULLUP); 
}

void loop() {
  int switchState = digitalRead(floatSwitchPin);

  if (switchState == LOW) {
    Serial.println("Reservoir Full");
  } else {
    Serial.println("Reservoir Empty");
  }
  delay(100);
}

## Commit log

2026-07-09 Working code for prototype 1
2026-07-10 Added a soil moisture sensor, lightly cleaned code, and updated DevLog.
2026-07-13 Prototyped the watering system
    Without putting holes in the tube, I prototyped the watering system using some Arduino code that turned the pump on when I pressed a button.
2026-07-13 CAD test designs
    These are the CAD designs for the clips that will hold the tubing, the temporary housing for the Arduino 9-volt battery, and the Relay module.
    [Arduino Prototype Housing - Test.stl, Watering Tubing Clip - Test.stl]
2026-07-13 Updated devlog, added decisions document, uploaded prototype version 1 vision
2026-07-18 Code additions
    Redid project code to utilize new sensors
2026-07-18 New CAD models
    New models for tube routing clips and the soil moisture sensor holder.
    [Soil Moisture Sensor Holder - Test.stl, Update Tube Routing Clips.stl]
2026-08-15 Added new CAD designs
    [Drainage hole Aligners.stl, Pump holder v1.stl, Pump holder v2.stl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]
2026-09-15 Overhaul project documentation and add test data
    [Data Testing - DataTest1 - Remove and Replace.csv, Data Testing - DataTest2 - Steady Decline.csv, Data Testing - DataTest3 - Remove and Replace.csv]
